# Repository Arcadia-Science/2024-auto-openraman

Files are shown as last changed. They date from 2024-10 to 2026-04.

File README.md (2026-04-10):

# AutoOpenRaman

This repo contains a Python package called `autoopenraman`. It uses Micro-Manager and Pycro-Manager to interface with the OpenRaman spectrometer. It provides a UI for spectrum visualization and uses the Pycro-Manager backend to control additional hardware. For more details, see our pub ["AutoOpenRaman: Low-cost, automated Raman spectroscopy"](https://doi.org/10.57844/arcadia-7vbd-n3ry).

neon-livemode-trimmed-cropped

## Reproducing figures

To reproduce the plots from **Figure 4** of the pub, from the main code directory run:

```bash
cd notebooks
uv run jupyter notebook analyze-chlamy-plate.ipynb
```

Figures will be plotted inline and saved to `figs/random_spectra_plot.pdf` and `figs/nmf_plot.pdf`.

## Requirements

- A computer running Windows (tested), macOS (tested), or Linux (*warning: not tested*), Python 3.10-3.12
- [OpenRAMAN spectrometer](https://www.open-raman.org/) camera (Blackfly BFS-U3-31S4M-C; FLIR), connected to the PC by USB. Alternatively, any camera [supported by Micro-Manager](https://micro-manager.org/Device_Support) can be used.
- [Micro-Manager 2.0](https://micro-manager.org/Micro-Manager_Nightly_Builds)

### Optional Hardware
- XY stage for multi-position acquisition
- Arduino/Teensy-controlled shutter device for controlling laser exposure
- Arduino/Teensy-controlled neon light source for rough calibration

The Arduino firmware for the shutter and neon light source is available in the `arduino` directory of this repository. You can upload it to your Arduino/Teensy board using the Arduino IDE.

## Installation

First, make sure you have [uv](https://docs.astral.sh/uv/getting-started/installation/) installed.

Then, clone the repository and install dependencies:
```bash
git clone https://github.com/Arcadia-Science/2024-auto-openraman
cd 2024-auto-openraman
uv sync
```

## Usage

Download the latest version of [Micro-Manager 2.0](https://micro-manager.org/Micro-Manager_Nightly_Builds) compatible with your OS. This package was built around `Micro-Manager 2.0.3-20250602` but should work with subsequent nightly builds.

Start Micro-Manager with the configuration `autoopenraman_mmconfig_demo.cfg` found in the root directory of this repo. No physical devices need to be connected to run tests.

In Micro-Manager, go to Tools>Options and enable the checkbox "Run pycro-manager server on port 4827". You will only need to do this once.

After installation, launch the application GUI with:

```bash
uv run autoopenraman
```

## Features

The GUI provides a unified interface where you can switch between:
- **Live Mode**: Real-time spectrum visualization with filtering options
- **Acquisition Mode**: Configure and run automated acquisitions across multiple positions

### Live Mode Features
- **Real-time visualization**: Continuous spectrum display from the spectrometer
- **Background subtraction**: Capture, store, and subtract background spectra to highlight sample features
- **Median filtering**: Apply configurable kernel size median filtering to reduce noise
- **X-axis reversal**: Option to reverse the x-axis for compatibility with different spectrometer orientations

### Acquisition Mode Features
- **Multi-position acquisition**: Acquire spectra at multiple stage positions defined in a Micro-Manager position list file
- **Spectra averaging**: Configurable number of acquisitions to average per position
- **Position randomization**: Option to randomize the order of stage positions during acquisition
- **Timelapse acquisition**: Configure multiple time points with specified intervals
- **Automatic file saving**: Saves spectra and metadata to CSV and JSON files

### Calibration Features
- **Wavenumber calibration**: Two-step calibration process using neon lamp and acetonitrile reference spectra
- **Save/load calibrations**: Save calibration for later use or load previously saved calibrations
- **Adjustable excitation wavelength**: Configure the excitation wavelength for accurate Raman shift calculation

## Profile Configuration

AutoOpenRaman uses `profile.yml` to track hardware connections and configurations. On first run, the package automatically copies `sample_profile.yml` from the repository to `~/autoopenraman/profile.yml` (Mac/Linux) or `%USERPROFILE%\autoopenraman\profile.yml` (Windows).

The profile includes the following key settings:

```yaml
# Default environment (testing or deployment)
environment: testing

# Testing environment settings (uses simulated devices)
testing:
  shutter_name: DemoShutter

# Deployment environment settings (for real hardware)
deployment:
  shutter_name: ArduinoShutter  # Replace with your actual shutter device name
```

When using real hardware, it is recommended to set the environment to `deployment` in the `profile.yml` file and update the corresponding section with your hardware information.

Set `save_dir` to the default directory where you want to save the acquired spectra. This directory will be created if it does not exist.

If using a real shutter, set `shutter_name` to match the name of the shutter in Micro-Manager.

## Calibration

AutoOpenRaman provides a two-step calibration process to convert from pixel coordinates to Raman shift (wavenumbers):

1. **Rough calibration** using a neon lamp spectrum to establish the coarse pixel-to-wavelength relationship
2. **Fine calibration** using acetonitrile reference spectrum to convert wavelengths to Raman shifts

### Calibration Procedure

1. In the GUI, click the "Calibrate" button
2. Select a neon lamp reference spectrum file (CSV format)
3. Select an acetonitrile reference spectrum file (CSV format)
4. Enter the excitation laser wavelength (default: 532 nm)
5. Click "Calibrate" to perform the calibration
6. Use "Save Calibration" to save the calibration for future use

The software identifies peaks in these reference spectra and matches them to known reference values:
- Neon peaks at specific wavelengths (585.249 - 653.288 nm)
- Acetonitrile peaks at specific Raman shifts (918, 1376, 2249, 2942, 2999 cm⁻¹)

After calibration, you can switch between "Pixels" and "Wavenumbers (cm⁻¹)" display modes using the dropdown menu.

### Data Output Format

#### Spectrum Files
Spectra are saved in CSV format with either 2 or 3 columns:
- Without calibration: `Pixel, Intensity`
- With calibration: `Pixel, Wavenumber (cm⁻¹), Intensity`

#### Metadata Files
Each spectrum has an accompanying JSON metadata file with the same base filename (but `.json` extension) containing:

1. **Acquisition Parameters**:
   - `Number of averages`: Number of spectra averaged for each measurement
   - `Stage position file`: Path to the position list file used
   - `DateTime`: Timestamp of acquisition (YYYY-MM-DD HH:MM:SS)

2. **Timelapse Information**:
   - `NumTimePoints`: Number of time points in the timelapse
   - `TimeIntervalSeconds`: Interval between time points in seconds

3. **Processing Parameters**:
   - `MedianFilter`: Settings for filtering (`Applied` boolean and `KernelSize`)
   - `ReverseX`: Whether the X-axis was reversed

4. **Calibration Information**:
   - `Applied`: Whether calibration was applied
   - `ExcitationWavelength`: Laser wavelength in nm (if calibrated)

5. **Position Information**:
   - `PositionName`: Name of the stage position from MM position list
   - Time point information from the acquisition

This metadata provides complete context for interpreting each spectrum and reproducing acquisition settings.

## Development

Follow the installation instructions above to set up the development environment.

### Testing

Make sure Micro-Manager is running with the demo configuration before running the tests. If `profile.yml` does not yet exist in `~/autoopenraman/`, it will be created automatically from the sample on first import.

We use `pytest` for testing. The tests are found in `autoopenraman/tests/test_gui.py`. To run the tests, run the following command from the root directory of the repository:

```bash
pytest -v
```

### Managing dependencies

We use uv to manage dependencies. To add a new dependency, use the following command:

```bash
uv add some-package
```

To add a new development dependency, use the following command:

```bash
uv add --dev some-dev-package
```

To update a dependency, use the following command:

```bash
uv lock --upgrade-package some-package
uv sync
```

Whenever you add or update a dependency, uv will automatically update both `pyproject.toml` and the `uv.lock` file. Make sure to commit the changes to these files to the repo.

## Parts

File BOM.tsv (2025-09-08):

Item Name | Quantity | Manufacturer / Source | Part Number / Identifier | Unit Price (USD) | Price (USD) | Source | Notes
OpenRAMAN Starter Edition | 1 | OpenRAMAN Project | Starter Edition | $2,600.00 | $2,600.00 | https://www.open-raman.org/build/starter-edition/download/
Ø1" Protected Silver Mirror | 1 | Thorlabs | PF10-03-P01 | $60.20 | $60.20 | https://www.thorlabs.us/thorProduct.cfm?partNumber=PF10-03-P01
Right-Angle Mirror Mount | 1 | Thorlabs | KCB1 | $165.48 | $165.48 | https://www.thorlabs.us/thorProduct.cfm?partNumber=KCB1
Microscope Objective | 1 | Nikon | Plan Apo λ 4x/0.20 NA | $1,200.00 | $1,200.00 | https://www.spachoptics.com/Nikon-CFI-Plan-Apo-4x-Lambda-Objective-p/nikon-mrd00045.htm | Cheaper used objectives can also be purchased
RMS-Threaded Cage Plate | 2 | Thorlabs | CP42 | $38.51 | $77.02 | https://www.thorlabs.com/thorProduct.cfm?partNumber=CP42
Cage Rods 1in | 8 | Thorlabs | EC1 | $4.00 | $32.00 | https://www.thorlabs.com/thorProduct.cfm?partNumber=EC1
Aluminum Breadboard 300x300mm | 1 | Thorlabs | MB3030/M | $184.49 | $184.49 | https://www.thorlabs.us/thorProduct.cfm?partNumber=MB3030/M
Pillar Post Ø25mm 38mm | 4 | Thorlabs | RS38P4/M | $28.70 | $114.80 | https://www.thorlabs.com/thorProduct.cfm?partNumber=RS38P4/M
Adjustable Height Post Base | 4 | Thorlabs | RB2/M | $40.36 | $161.44 | https://www.thorlabs.de/thorProduct.cfm?partNumber=RB2/M
Manual Lab Jack | 1 | Thorlabs | L490 | $760.11 | $760.11 | https://www.thorlabs.us/thorProduct.cfm?partNumber=L490
Motorized XY Stage | 1 | Prior Scientific (used) | H7550T | $1,745.00 | $1,745.00 | N/A | Estimate from eBay; verify compatibility with µManager
Stepper Motor and driver board | 1 | Amazon | B07VPD4KJD | $2.96 | $2.96 | https://www.amazon.com/4-Phase-Stepper-ULN2003-Machinery-Raspberry/dp/B07VPD4KJD
Microcontroller | 2 | DigiKey | Teensy 4.0 | $41.92 | $83.84 | https://www.digikey.ca/en/maker/platforms/t/teensy
Neon Indicator Light | 1 | VCC / DigiKey | 1050QC2 | $5.85 | $5.85 | https://www.mouser.com/ProductDetail/VCC/1050QC2
Fiber Optic Patch Cable | 1 | Thorlabs | M53L02 | $113.00 | $113.00 | https://www.thorlabs.com/thorproduct.cfm?partnumber=M53L02 | Cheaper fiber optics can be used
FC/PC Fiber Adapter Plate | 2 | Thorlabs | SM1FC2 | $27.00 | $54.00 | https://www.thorlabs.us/thorProduct.cfm?partNumber=SM1FC2
Relay Module | 1 | Amazon | B00E0NTPP4 | $7.00 | $7.00 | N/A | Estimate
Project Box | 2 | Amazon | B08P55BZDH | $10.00 | $20.00 | N/A | Estimate
Aluminum Extrusion | 4 | McMaster-Carr | 5537T926 | $10.00 | $40.00 | N/A | Estimate
Black Cardboard | 4 | Local/Generic | N/A | $2.00 | $8.00 | Generic material; price varies | Estimate
 |  |  |  | TOTAL | $7,435.19

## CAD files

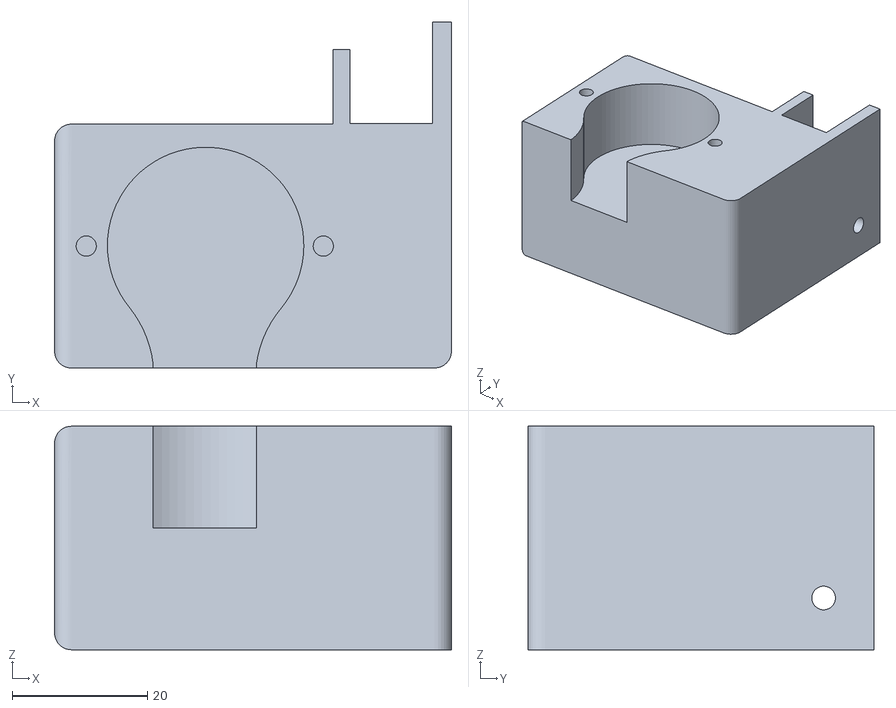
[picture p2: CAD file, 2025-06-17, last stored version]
CAD/stepper-motor-fixture.stl
58.6 x 51.1 x 33.0

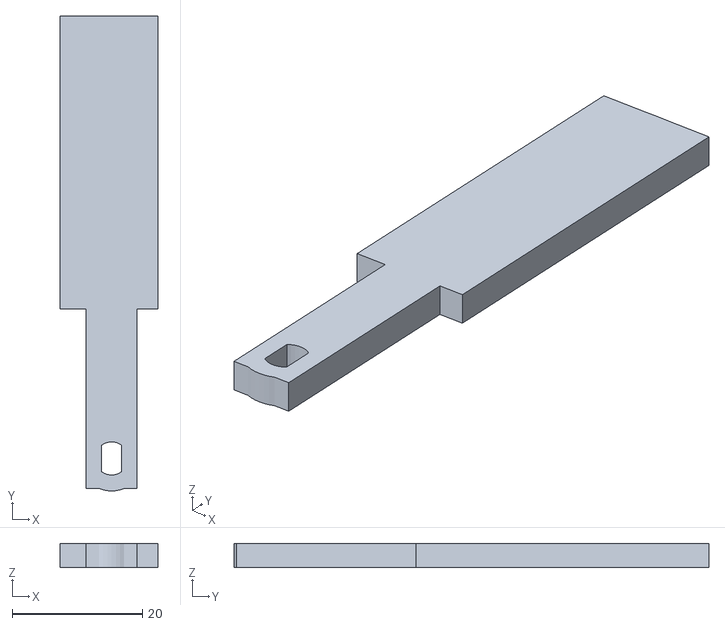
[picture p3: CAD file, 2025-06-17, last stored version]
CAD/shutter-paddle.stl
15.0 x 73.0 x 3.70

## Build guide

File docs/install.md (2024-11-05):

# Installation

You could, for example, have a page like this that describes how to install the package.

## Using pip

AutoOpenRaman Documentation is hosted on the [Python Package Index (PyPI)](https://pypi.org/project/AutoOpenRaman Documentation/) and can be installed with pip.

```{eval-rst}
.. tabs::

   .. tab:: **Linux**

      .. code-block:: bash

         pip install autoopenraman

   .. tab:: **MacOS**

      .. code-block:: bash

         pip install autoopenraman

   .. tab:: **Windows**

      .. code-block:: bash

         pip install autoopenraman
```

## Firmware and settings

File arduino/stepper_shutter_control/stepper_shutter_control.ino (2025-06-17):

//=========================================================
// Stepper Motor Shutter Controller
// Controls a stepper-motor-based shutter via serial commands
//=========================================================

#include <Stepper.h>

//========================== Constants ==========================
const int STEPS_TO_MOVE = 200;         // Number of steps to fully open/close the shutter
const int STEPPER_SPEED_RPM = 80;      // Speed of the stepper motor in RPM

const byte BUFFER_SIZE = 40;           // Max size of input buffer
const char START_MARKER = '<';         // Start of command
const char END_MARKER = '>';           // End of command

//======================= State Variables =======================
Stepper myStepper(STEPS_TO_MOVE, 8, 10, 9, 11);  // Motor wired to pins 8, 10, 9, 11
bool shutterOpen = false;                        // Tracks shutter state

char inputBuffer[BUFFER_SIZE];           // Raw input buffer
char messageFromPC[BUFFER_SIZE] = {0};   // Parsed command message

byte bytesReceived = 0;
bool readInProgress = false;
bool newDataFromPC = false;

//===================== Timing (unused, placeholder) =====================
unsigned long curMillis;
unsigned long prevReplyToPCMillis = 0;
unsigned long replyToPCInterval = 1000;

//=========================================================
void setup() {
  Serial.begin(9600);
  myStepper.setSpeed(STEPPER_SPEED_RPM);

  shutterOpen = false;

  // Notify PC that setup is complete
  Serial.println("<INI>");
}

//=========================================================
void loop() {
  curMillis = millis();
  getDataFromPC();    // Check for incoming serial commands
  updateShutter();    // Act on commands if any
}

//=========================================================
// Reads data from the serial buffer enclosed in < and >
void getDataFromPC() {
  while (Serial.available() > 0) {
    char x = Serial.read();

    if (x == START_MARKER) {
      bytesReceived = 0;
      readInProgress = true;
    }
    else if (x == END_MARKER) {
      readInProgress = false;
      newDataFromPC = true;
      inputBuffer[bytesReceived] = '\0'; // Null-terminate string
      parseData();
    }
    else if (readInProgress && bytesReceived < BUFFER_SIZE - 1) {
      inputBuffer[bytesReceived++] = x;
    }
  }
}

//=========================================================
// Parses the inputBuffer into a command message
void parseData() {
  strcpy(messageFromPC, inputBuffer);
}

//=========================================================
// Sends an acknowledgement to the PC
void replyAck() {
  if (newDataFromPC) {
    newDataFromPC = false;
    Serial.println("<ACK>");
  }
}

// Sends current shutter status to PC
void replyShutterStatus() {
  if (newDataFromPC) {
    newDataFromPC = false;
    Serial.println(shutterOpen ? "<STO>" : "<STC>");
  }
}

// Resets the shutter state without moving the motor
void replyReset() {
  if (newDataFromPC) {
    newDataFromPC = false;
    Serial.println("<INI>");
    shutterOpen = false;
  }
}

//=========================================================
// Interprets commands and acts accordingly
void updateShutter() {
  if (newDataFromPC) {
    if (strcmp(messageFromPC, "OPE") == 0) {  // Open shutter
      if (!shutterOpen) {
        myStepper.step(STEPS_TO_MOVE);
        delay(3000); // Allow mechanical settling
      }
      shutterOpen = true;
      replyAck();
    }
    else if (strcmp(messageFromPC, "CLS") == 0) {  // Close shutter
      if (shutterOpen) {
        myStepper.step(-STEPS_TO_MOVE);
        delay(3000); // Allow mechanical settling
      }
      shutterOpen = false;
      replyAck();
    }
    else if (strcmp(messageFromPC, "STA") == 0) {  // Status
      replyShutterStatus();
    }
    else if (strcmp(messageFromPC, "RES") == 0) {  // Reset
      replyReset();
    }
  }
}

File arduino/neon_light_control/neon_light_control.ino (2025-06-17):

//=========================================================
// Neon Light Source Controller
// Controls a calibration neon light source via a relay
// Communication with PC via Serial for command handling
//=========================================================

bool lightOn = false; // Tracks the ON/OFF state of the neon light

//========================= Constants =========================
const int RELAY_CONTROL_PIN = 13;  // Pin on Teensy that controls the relay
const byte BUFFER_SIZE = 40;       // Max size of incoming serial buffer

const char START_MARKER = '<';     // Indicates start of command
const char END_MARKER = '>';       // Indicates end of command

//====================== Serial Buffers =======================
char inputBuffer[BUFFER_SIZE];     // Temporary buffer for incoming characters
char messageFromPC[BUFFER_SIZE] = {0};  // Parsed message from PC

//=================== Serial Parsing State ====================
byte bytesReceived = 0;
bool readInProgress = false;
bool newDataFromPC = false;

//===================== Timing Variables ======================
unsigned long curMillis;
unsigned long prevReplyToPCMillis = 0;
unsigned long replyToPCInterval = 1000; // Not currently used

//=========================================================
void setup() {
  Serial.begin(9600);

  pinMode(RELAY_CONTROL_PIN, OUTPUT);

  // The light is connected to a Normally Closed (NC) terminal on the relay
  // The relay is active HIGH: HIGH = light ON, LOW = light OFF
  // Start with the light OFF
  digitalWrite(RELAY_CONTROL_PIN, LOW);
  lightOn = false;

  // Notify PC that device is initialized
  Serial.println("<INI>");
}

//=========================================================
void loop() {
  curMillis = millis();
  getDataFromPC();  // Read command from PC if available
  updateLight();    // Take action based on received command
}

//=========================================================
// Reads incoming data between START_MARKER and END_MARKER
void getDataFromPC() {
  while (Serial.available() > 0) {
    char x = Serial.read();

    if (x == START_MARKER) {
      bytesReceived = 0;
      readInProgress = true;
    }
    else if (x == END_MARKER) {
      readInProgress = false;
      newDataFromPC = true;
      inputBuffer[bytesReceived] = '\0'; // Null-terminate the string
      parseData();
    }
    else if (readInProgress) {
      if (bytesReceived < BUFFER_SIZE - 1) {
        inputBuffer[bytesReceived++] = x;
      }
    }
  }
}

//=========================================================
// Copies validated input into the message buffer
void parseData() {
  strcpy(messageFromPC, inputBuffer);
}

//=========================================================
// Sends a generic ACK reply to PC
void replyAck() {
  if (newDataFromPC) {
    newDataFromPC = false;
    Serial.println("<ACK>");
  }
}

// Sends current light status to PC
void replyLightStatus() {
  if (newDataFromPC) {
    newDataFromPC = false;
    Serial.println(lightOn ? "<LON>" : "<LOF>");
  }
}

// Resets light to OFF and notifies PC
void replyReset() {
  if (newDataFromPC) {
    newDataFromPC = false;
    Serial.println("Resetting neon light to OFF");
    digitalWrite(RELAY_CONTROL_PIN, LOW);
    lightOn = false;
    Serial.println("<INI>");
  }
}

//=========================================================
// Interprets and responds to commands received from PC
void updateLight() {
  if (newDataFromPC) {
    if (strcmp(messageFromPC, "OPE") == 0) {  // Turn light ON
      if (!lightOn) {
        digitalWrite(RELAY_CONTROL_PIN, HIGH);
        lightOn = true;
      }
      replyAck();
    }
    else if (strcmp(messageFromPC, "CLS") == 0) {  // Turn light OFF
      if (lightOn) {
        digitalWrite(RELAY_CONTROL_PIN, LOW);
        lightOn = false;
      }
      replyAck();
    }
    else if (strcmp(messageFromPC, "STA") == 0) {  // Report Status
      replyLightStatus();
    }
    else if (strcmp(messageFromPC, "RES") == 0) {  // Reset
      replyReset();
    }
  }
}

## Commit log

2024-10-22 small mod to account for real stage
2024-10-24 move stage args to AcquisitionManager
2024-10-26 switch to click, add basic tests
2024-10-27 modify live test case to exit by itself in debug
2024-11-06 add acq tests with stage positions
2024-11-15 cam acquisition to thread (#14)
2024-11-20 randomize stage positions in acq
2024-12-09 fix stage label type in Acquisition (#19)
2025-02-24 README update, add demo MM config
    [autoopenraman_mmconfig_demo.cfg]
2025-03-09 Merge live and acquisition modes into a unified GUI
    - Created a new unified GUI (AutoOpenRamanGUI) that combines both modes
    - Added ability to switch between live and acquisition modes in a single interface
    - Added file dialogs for selecting position files and experiment directories
    - Updated CLI to make unified GUI the default when running `autoopenraman`
    - Maintained backward compatibility with original CLI commands
    - Added tests for the new GUI implementation
2025-03-09 Consolidate GUI with shared plot and filter controls
    - Modified GUI to use a single shared PlotWidget for both live and acquisition modes
    - Moved filter controls (reverse X, median filter) to a common section
    - Added filter parameters to acquisition metadata
    - Wrote a common spectrum processing function for consistent behavior
    - Updated tests to match the new GUI structure
2025-03-09 Improve acquisition mode to display running average in real-time
    - Modified acquisition mode to display both current measurement and running average
    - Added a checkbox to toggle display of current measurement alongside the average
    - Enhanced plot handling with dedicated colors for different data series
    - Added proper plot initialization when switching between modes
    - Improved plot labels and titles to better indicate what data is being shown
    - Added QApplication.processEvents() to ensure immediate UI updates
2025-03-22 add device control Arduino code
2025-04-28 remove CLI, update config_profile
    - CLI removed to streamline codebase, still used in other branches
    - config_profile updated to require spectrometer field (will only be openraman in this case)
2025-04-29 Wavenumber calibration implemented
    1. Added a RamanCalibrator class to utils.py that implements calibration based on the ramanalysis approach:
    - Rough calibration using neon spectral peaks
    - Fine calibration using acetonitrile reference peaks
    - Functions to save and load calibration data
    2. Updated the GUI with calibration-related controls:
    - Added an X-axis mode selector (Pixels or Wavenumbers)
    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
2025-04-29 Implement background subtraction in Live mode
    1. Added Background Storage and Management:
    - Added Store Background and Clear Background buttons to Live Mode Controls
    - Added a status label that shows whether background subtraction is active
    - Created methods to store and clear the background spectrum
    - Changed the plot color to green when background subtraction is active
    2. Enhanced the Camera Worker Thread:
    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
2025-05-05 Fix background-subtraction clipping negative values (#24)
    - Convert camera images to float64
    - Remove np.maximum clipping statement
    - Add test case
2025-05-05 Fix browse button argument (#25)
    - config_profile.save_dir turned to a string for compatibility with QFileDialog.getExistingDirectory
    - Tested on Mac
2025-05-15 README update, simplify config file
    * Added calibration and metadata details to README
    * Config file no longer needs `spectrometer` and `simulate_spectrometer` fields (they are no longer used)
    * moved calibration constants to top of `utils.py`
2025-05-23 Add stepper motor CAD files
    [shutter-paddle.stl, stepper-motor-fixture.stl]
2025-06-02 Modularize calibration code
2025-06-02 Pin pyqt5-qt5 requirement for Windows compatibility
2025-06-13 Add documentation for Arduino code (#28)
    - Renamed devices folder to arduino for clarity
    - Cleaned up Arduino code, added docs
    - Added reference to arduino in README
2025-06-17 Refactor README and code comments for clarity; update calibration loading logic and improve test setup
2025-06-17 Remove CAD files from repo
    [shutter-paddle.stl, stepper-motor-fixture.stl]
2025-09-08 Fix CITATION, add BOM
    [BOM.tsv]
2026-04-10 Switch to uv instead of poetry
2026-04-10 Address repro checker (#38):
    * Automatically copy profile to user dir, fail gracefully if error
    * Pin dependencies in pyproject, pin pycromanager to pypi release, not HEAD
    * Add random seed to notebook
    * Docs: mention running the notebook
    * Docs: installation instructions using uv
2026-04-10 Fix sample_config copy behavior; save_dir path
    * sample_config.yml now included as resource
    * undefine save_dir in sample_config so that data is not written to code dir
